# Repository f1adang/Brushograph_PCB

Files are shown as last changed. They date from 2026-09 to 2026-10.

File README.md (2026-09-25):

# Brushograph PCB

This repository contains the KiCad PCB design files for the Brushograph (miniPenzlograf) project, a pen-plotting device designed for creating artistic drawings and patterns.

**A manufacturing-ready PCB-design to run FluidNC on ESP32 including ULN2003 drivers for 3 uni-polar stepper motors (28byj-48)**

Brushograph PCB

**A DIY etchable PCB-design to run FluidNC on ESP32 including ULN2003 drivers for 3 uni-polar stepper motors (28byj-48)**

Brushograph PCB

## About Brushograph

This PCB repository is part of the larger Brushograph project, which explores "Ways of painting with a mechatronic brush" - an intersection between classical artistic techniques and modern technology.

**Main Documentation:**
- [Brushograph Wiki](https://wiki.sgmk-ssam.ch/wiki/Brushograph) - Complete project documentation

## Project Structure

- `Brusograf_PCB/` - Original KiCad project (DIY etchable, single layer)
  - `MASK/` - Mask files in SVG and PDF for PCB silkscreen
- `Brushograf_PCB-china/` - Rev A: manufacturing-ready project and Gerbers
  - `Gerber_Brusograf_black.zip` - Zipped Gerbers ready to upload to a PCB manufacturer
- `Brushograf_PCB-revB/` - Rev B: work in progress (see "Rev B" below)
- `FluidNC_config/` - Configuration for FluidNC firmware
  - `config_pink.yaml` - Rev A config
  - `config_revB.yaml` - Rev B config, adds the pendant UART
- `photos/` - Project photos and documentation images

## Rev B (in progress)

`Brushograf_PCB-revB/` replaces the power section with a USB-C Power Delivery
supply feeding an adjustable motor rail, and adds a pendant port and an ESP
power switch.

**Schematic: complete and verified. PCB: all parts placed, routing still to do.**

The board grows from **198 x 48mm to 198 x 73mm** - 25mm added along the top
edge. Everything from rev A keeps its coordinates; all the new parts live in
the new strip. The RJ-12 needs about 19mm of depth behind the top edge and the
old board only had 11mm before the back-side SPI tracks, which is what forced
the growth.

### What rev B adds

**USB-C Power Delivery is now the only power inlet.** The barrel jack is gone,
along with its reverse-polarity FET and zener. J12 sits on the **left edge**
with the receptacle overhanging it; a CH224K sink controller (U6) requests
**9V**, set by the single 6.8k resistor R24 on CFG1 per the WCH datasheet. A
"PD OK" LED (D17) on the controller's power-good output shows when the contract
is up. VBUS reaches the converters through a 1.5A resettable fuse (F1).

PD offers no 7.5V fixed profile, so the 9V rail feeds two buck converters.

**Adjustable motor rail.** U7 (TPS54202, 2A) steps 9V down to the motor rail,
adjustable with trimmer RV1 over roughly **5.4 - 8.6V**, nominally 7.5V. The
divider is 100k on top and 7.5k plus the 10k trimmer below, against the
TPS54202's 0.596V reference. The wiper is tied to the top of the track, so a
lifted wiper drops the output rather than raising it.

> Running 5V-rated 28BYJ-48 motors at 7.5V is a deliberate overclock: about
> 300mA per motor with two phases energised, roughly 900mA for three. More
> torque and speed, but the motors will run noticeably warm. Set the trimmer to
> 5V first and work up.

**Separate 5V logic rail.** U8 (TPS54202) makes 5.07V for the ESP32. The DevKitC
cannot be fed 7.5V on its 5V pin - its onboard AMS1117 would burn about a watt -
so logic and motors get separate rails.

**ESP power switch.** SW1 is a panel **lever switch on the left edge**, actuator
overhanging the board. It is a 1P2T part used as a simple break: common to the
ESP32, one throw to the board's 5V, the other left open, so the far position
leaves the module running on its own USB supply while the rest of the board
stays powered. D14 (SS14) blocks USB 5V from back-feeding the logic buck.

**RJ-12 pendant port** on the **upper edge**, opening facing off the board. J13
brings UART1 out on GPIO 2 and 15 with switched 5V, behind a 0.5A resettable
fuse (F2), 330R series resistors and TVS clamps.

**J7 repurposed.** Pin 3 used to carry the raw barrel-jack rail straight to the
motors, which would have destroyed them with a 12V adapter. It now carries the
regulated adjustable rail; pin 1 is the 5V logic rail for testing, pin 2 the
motor rail.

### Status

| Area | State |
|---|---|
| Schematic | Complete. 75 parts, 120 nets, netlist verified net by net |
| ERC | At or below rev A in every category |
| Placement | All 36 new footprints placed, zones refilled |
| DRC | No new errors except on J12 - see below |
| Routing | **53 ratsnest connections outstanding** |

### Known DRC findings

- **J12 reports 27 `shorting_items` and 4 `hole_clearance` errors.** These are
  not caused by the placement: the same 31 errors appear with the untouched
  stock footprint alone on an otherwise empty board. The pads have genuine
  0.2-0.7mm gaps and nothing bridges them - zones, solder mask and neighbouring
  copper were each ruled out by experiment. Every USB-C footprint in the KiCad
  library has sub-0.25mm pad gaps, so swapping parts will not help. Worth
  opening in the GUI, where the marker shows interactively what it thinks is
  touching, before committing to fab.
- `allow_soldermask_bridges` is set on J12, which is the correct treatment for a
  fine-pitch connector and clears 23 mask-bridge errors.
- Everything else - 4 mounting-hole annular widths, U4's malformed courtyard,
  5 starved thermals - is inherited unchanged from rev A.

### Open questions

- **The RJ-12 pin order is unverified.** The board uses
  `1 = GND, 2 = +5V, 3 = TX, 4 = RX, 5 = +5V, 6 = GND`, chosen so a standard
  reversing modular cable keeps power and ground on the right contacts and swaps
  TX/RX. bdring's official FluidDial pinout could not be confirmed from public
  documentation - **check it against your cable before building**.
- GPIO2 is an ESP32 strapping pin. It must not be pulled high during boot or the
  chip enters download mode. An idle-high UART receiver at the pendant end is
  fine; anything that actively drives the line is not.

### Known issues carried over from rev A

- The `MISO` and `MOSI` net names are swapped relative to the SD card: net
  `MISO` (GPIO19) goes to the card's CMD/DI pin, which is physically MOSI. The
  card works and the FluidNC config is correct, but **J6's back silkscreen is
  mislabelled** - an external SD module wired to J6 per the silk will have DI
  and DO reversed.
- R1-R12 and C1-C3 still have no values in the schematic, so the BOM is not
  directly orderable.
- The four mounting holes are plated pads with zero annular ring and should be
  non-plated.

## Features

- Custom PCB design for the Brushograph device
- ESP32-based control board with FluidNC firmware support
- Integrated ULN2003 drivers for 3 uni-polar stepper motors (28byj-48)
- DIY etchable single-layer design for easy home fabrication
- Rounded PCB version available
- Configuration files for FluidNC firmware (custom fork for support uni-polar steppers)

## Hardware Configuration

### ESP32 Pin Configuration

Phase order below matches `FluidNC_config/config_revB.yaml`. Note it is the
reverse of what older revisions of this README listed - reversing the phase
order simply reverses the direction of travel.

#### X-Axis Motor (Unipolar)
- Phase 0: GPIO 27
- Phase 1: GPIO 14
- Phase 2: GPIO 13
- Phase 3: GPIO 4

#### Y-Axis Motor (Unipolar)
- Phase 0: GPIO 22
- Phase 1: GPIO 21
- Phase 2: GPIO 17
- Phase 3: GPIO 16

#### Z-Axis Motor (Unipolar)
- Phase 0: GPIO 32
- Phase 1: GPIO 33
- Phase 2: GPIO 25
- Phase 3: GPIO 26

#### SD Card (SPI)
- MOSI: GPIO 19  (net labelled `MISO` on the schematic - see Known issues)
- MISO: GPIO 23  (net labelled `MOSI` on the schematic - see Known issues)
- SCK: GPIO 18
- CS: GPIO 5

#### Pendant UART (rev B)
- TX: GPIO 2 (J13)
- RX: GPIO 15 (J13)

#### Still free
GPIO 34, 35, 36 and 39 (all input-only), GPIO 12, and UART0 on GPIO 1/3.

The four input-only pins are the natural place for limit switches if homing is
added later; they have no internal pull-ups, so each would need an external one.

### Motor Configuration

`config_revB.yaml` in the FluidNC_config directory carries the settings for the
stepper motors. There are no limit switches, so no homing cycles are defined and
every limit pin is `NO_PIN`:

- X/Y axis: 93 steps/mm, 1500 mm/min max rate, 80 mm/s2 acceleration
- Z axis: 108 steps/mm, 1000 mm/min max rate, 40 mm/s2 acceleration

### 28BYJ-48 Stepper Motors

The PCB is designed specifically for the commonly available and inexpensive 28BYJ-48 unipolar stepper motors:
- 5V DC operation
- Gear reduction ratio of 1:64
- Step angle of 5.625° (64 steps per revolution)
- 4-phase operation via ULN2003 driver

## Getting Started

To view or modify the PCB design:
1. Install KiCad (version 6.0 or later recommended)
2. Open the `.kicad_pro` project file in the `Brusograf_PCB` directory
     - For the latest manufacturing-ready version, you can also open the project in `Brushograf_PCB-china/`

For complete setup instructions, including firmware and mechanical assembly, please refer to the [Brushograph Wiki](https://wiki.sgmk-ssam.ch/wiki/Brushograph).

## Manufacturing-ready files

- Latest Gerbers (ZIP, ready for fab): [`Brushograf_PCB-china/Gerber_Brusograf_black.zip`](Brushograf_PCB-china/Gerber_Brusograf_black.zip)
- Gerber folder (all layers and drill files): [`Brushograf_PCB-china/Gerber_Brusograf/`](Brushograf_PCB-china/Gerber_Brusograf/)

## Related Repositories

- [FluidNC for unipolar steppers](https://git.kompot.si/g1smo/FluidNC) - Forked and reworked version of FluidNC to support uni-polar steppers

## License

[Specify license here]

## Credits

Designed by dusjagr

The Brushograph project is based on Dominik Mahnič's "Brušografia" concept, bridging traditional painting and technology.

## Contact

[Your contact information here]

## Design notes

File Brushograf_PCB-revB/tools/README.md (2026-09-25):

# Rev-B generation scripts

One-shot scripts used to derive the rev-B schematic and PCB from the rev-A
project (`../../Brushograf_PCB-china/`). They are kept for reference and so the
revision can be regenerated or audited; ordinary further editing should happen
in KiCad, not here.

Run order, starting from a fresh copy of the rev-A `.kicad_sch` / `.kicad_pcb`:

1. `edit_sch.py`  - sheet -> A2, motor-rail bulk cap, 5V system rail
2. `edit_sch2.py` - USB-C PD input, both buck converters, ESP lever switch,
                    RJ-12 pendant port, and removal of the old linear regulator
                    and barrel jack
3. `edit_pcb.py`  - grows the outline 25mm upward, places all 36 new parts
                    (auto-nudging each clear of existing copper) and re-nets
                    every pad from the exported netlist
4. `fillzones.py` - refills the copper pours. Needs KiCad's bundled Python:
                    /Applications/KiCad/KiCad.app/Contents/Frameworks/\
                    Python.framework/Versions/3.9/bin/python3

Between steps 2 and 3, export the netlist:

    kicad-cli sch export netlist --format kicadsexpr -o revB.net Brushograf_PCB-revB.kicad_sch

Support modules: `kisexp.py` (S-expression reader/writer), `symlib.py` (loads
library symbols and flattens `extends`), `schbuild.py` (symbol placement and
wiring by pin name), `pcbgeom.py` (board occupancy model used to check that a
footprint placement clears existing copper).

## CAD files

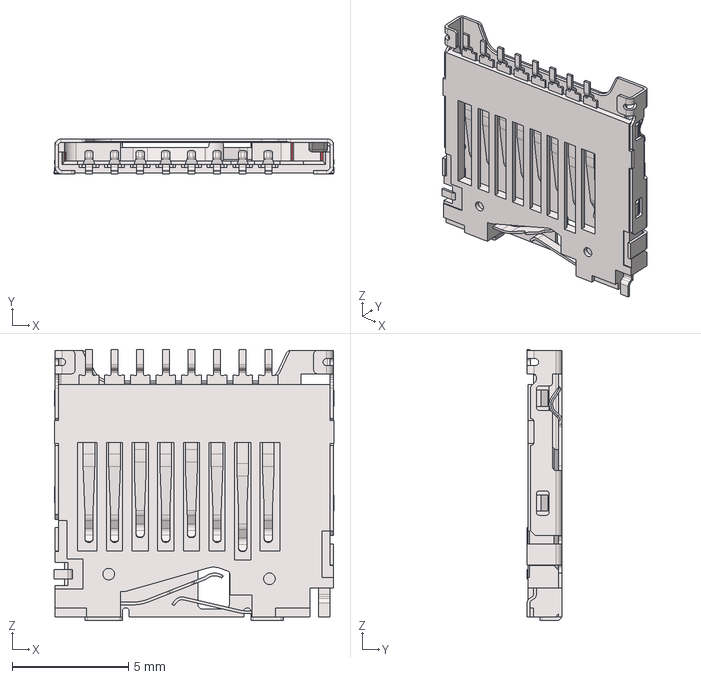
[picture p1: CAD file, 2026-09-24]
Brushograf_PCB-revB/footprints/3d/SD_CARD_MICRO_AMPHENOL_1140084168.step
12.0 x 1.50 x 11.7 mm

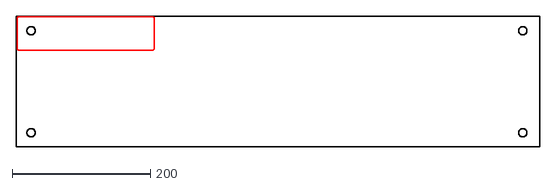
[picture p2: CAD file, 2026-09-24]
Brushograf_PCB-revB/svg2shenzhen/brushograf_edgeCut.dxf
755.9 x 189.0

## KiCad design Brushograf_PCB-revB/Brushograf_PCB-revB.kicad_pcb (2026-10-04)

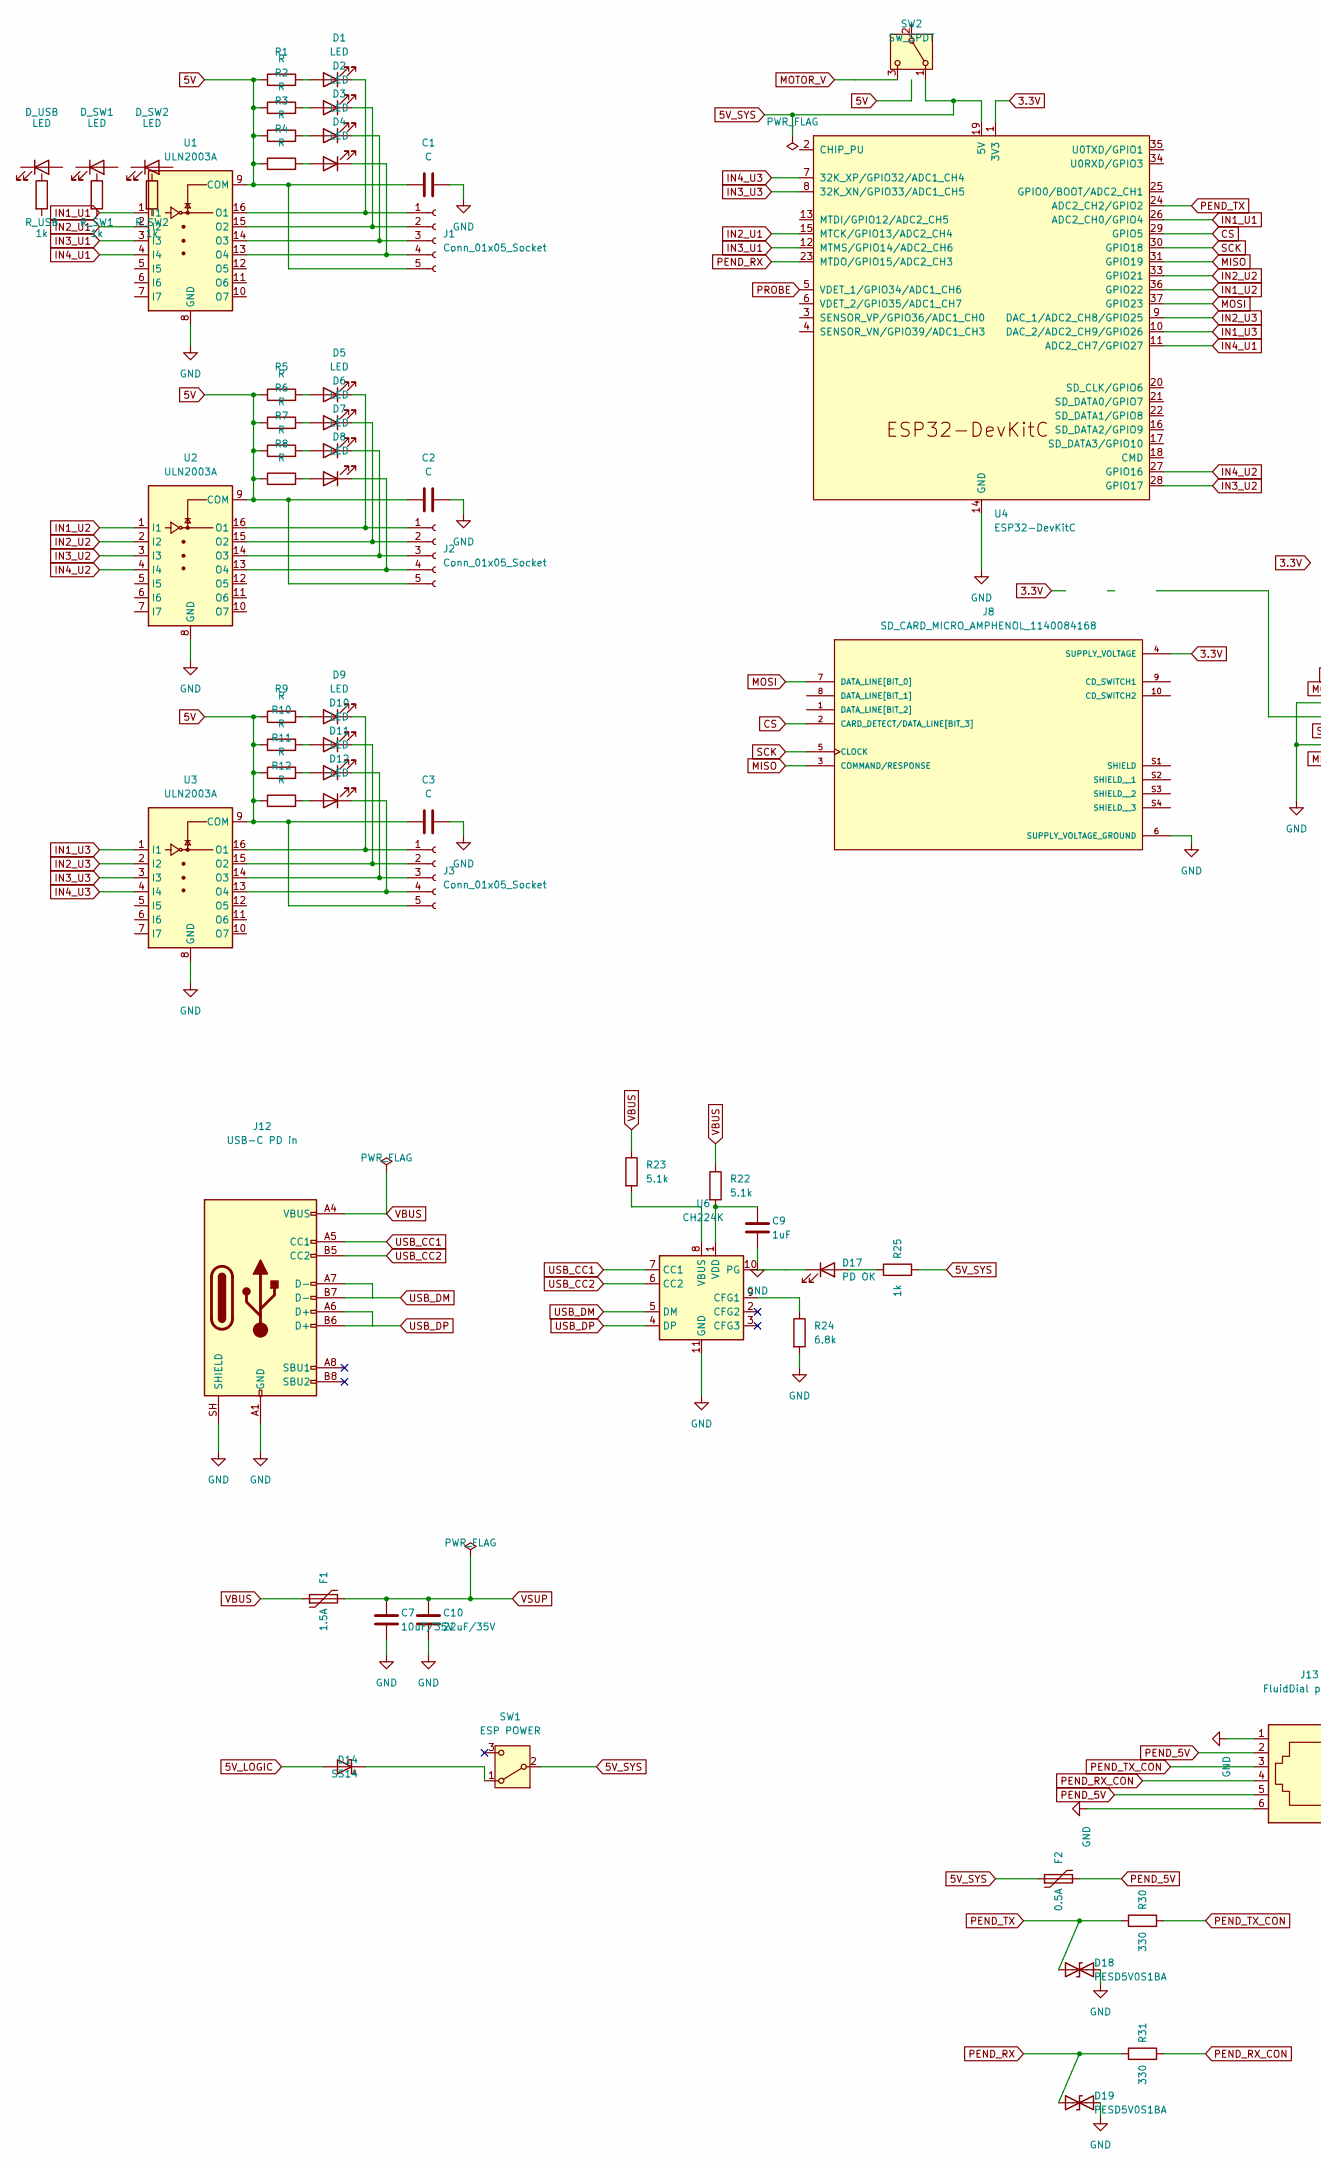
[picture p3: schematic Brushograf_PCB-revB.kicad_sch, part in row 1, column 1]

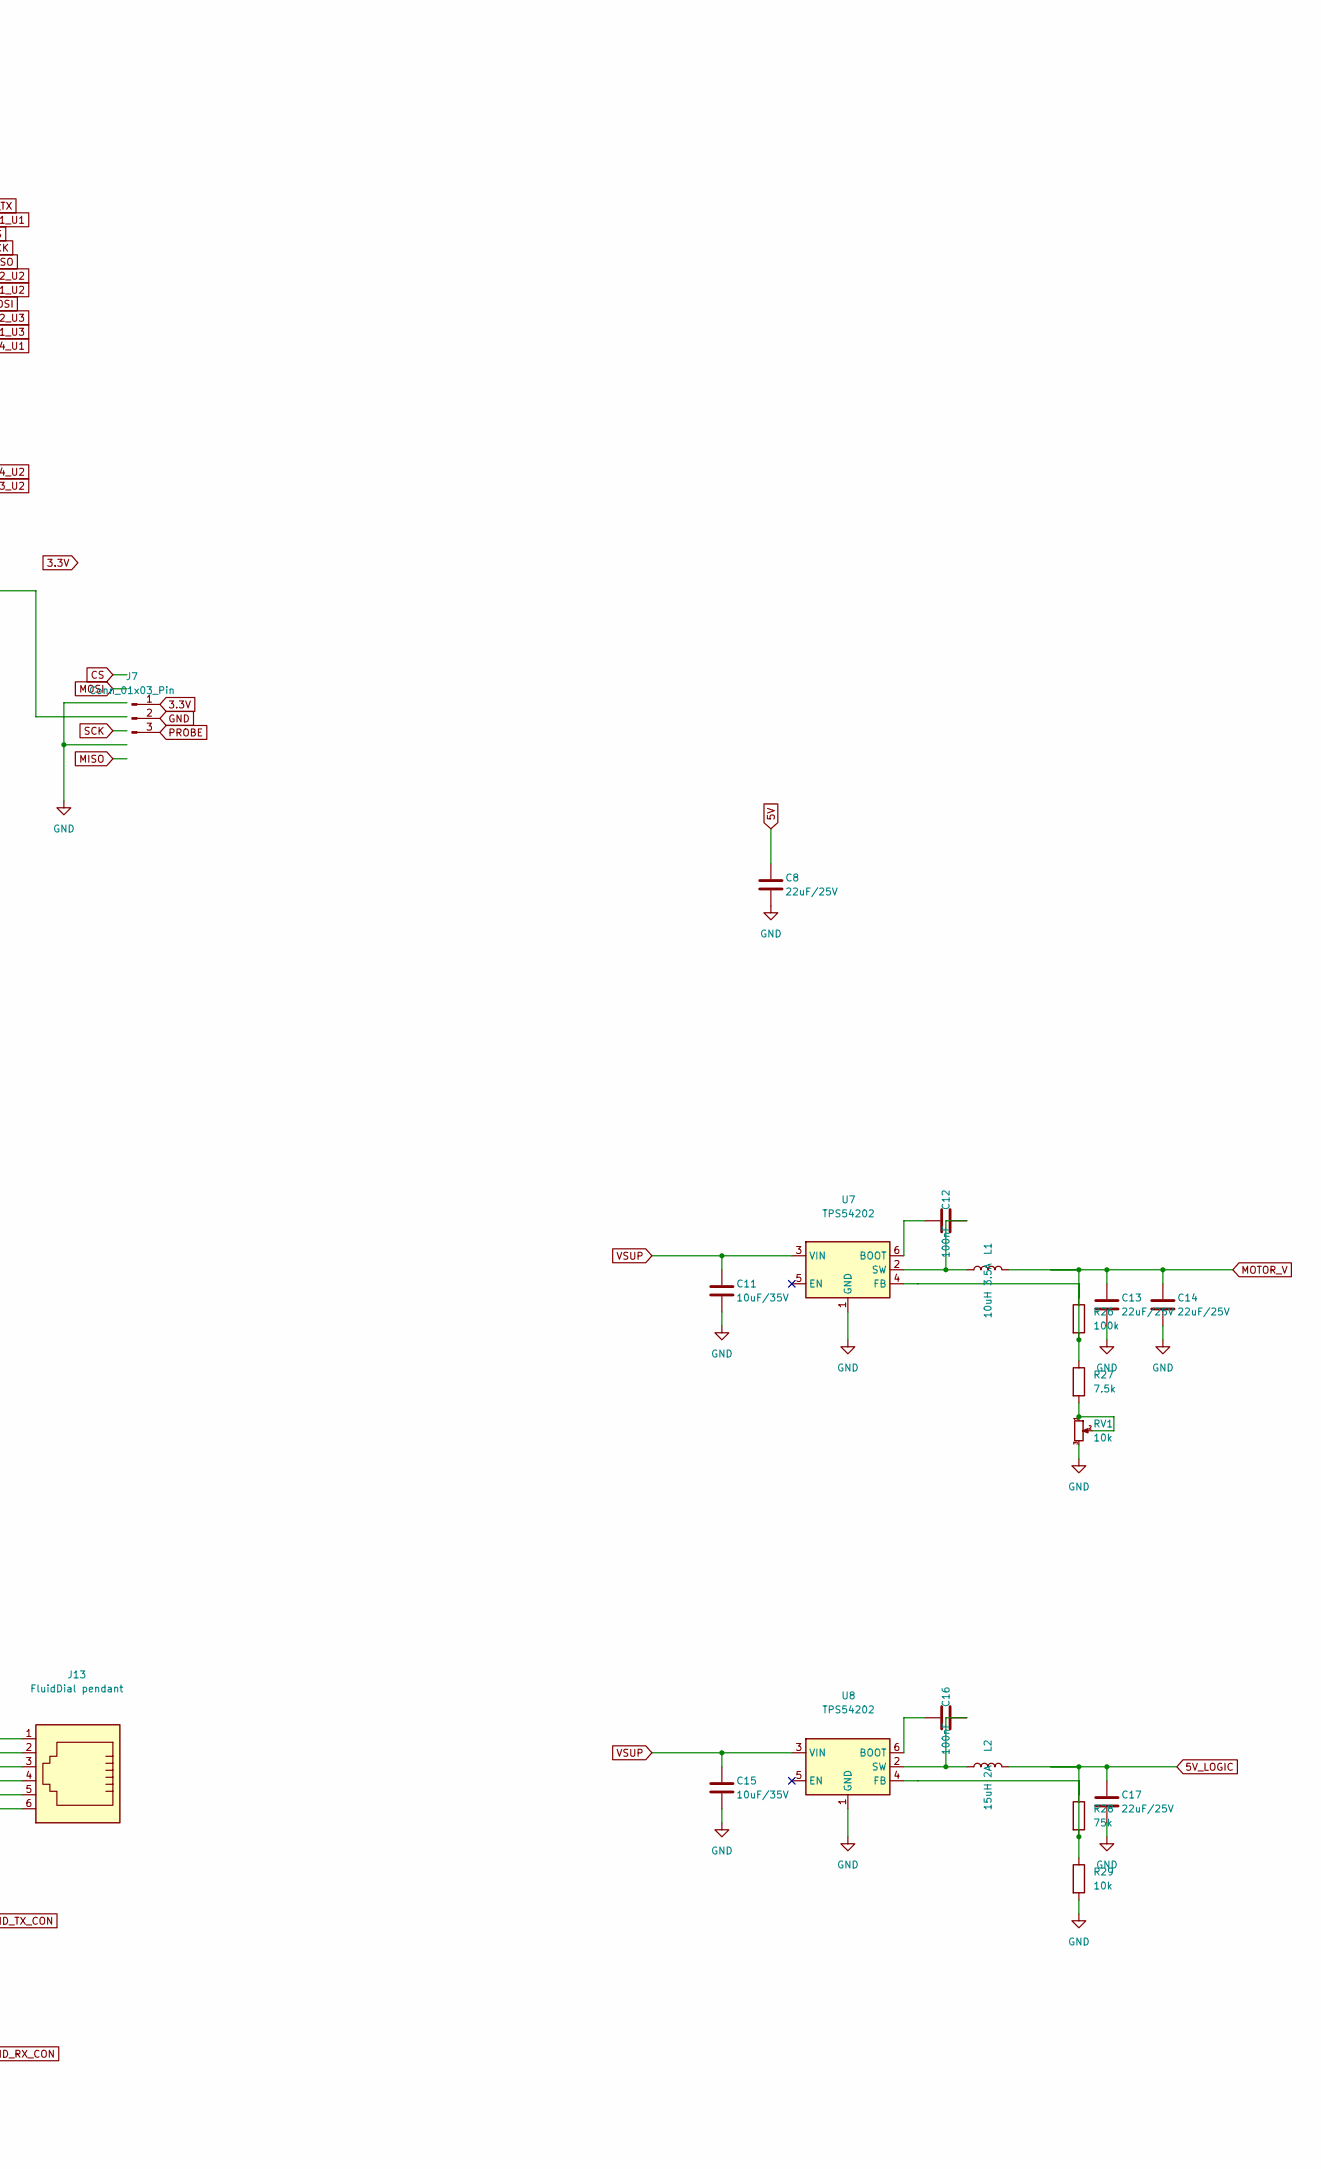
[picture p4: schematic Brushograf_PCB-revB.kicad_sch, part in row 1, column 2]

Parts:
C1, C2, C3: C; C_1210_noGND
C7: 10uF/35V; C_1206_3216Metric_Pad1.33x1.80mm_HandSolder
C8, C13, C14, C17: 22uF/25V; C_1210_3225Metric_Pad1.33x2.70mm_HandSolder
C9: 1uF; C_0603_1608Metric_Pad1.08x0.95mm_HandSolder
C10: 22uF/35V; C_1210_3225Metric_Pad1.33x2.70mm_HandSolder
C11, C15: 10uF/35V; C_1210_3225Metric_Pad1.33x2.70mm_HandSolder
C12, C16: 100nF; C_0603_1608Metric_Pad1.08x0.95mm_HandSolder
D1, D2, D3, D4, D5, D6, D7, D8, D9, D10, D11, D12: LED; LED_D1.8mm_W3.3mm_H2.4mm
D14: SS14; D_SMA_Handsoldering
D17: PD OK; LED_0805_2012Metric_Pad1.15x1.40mm_HandSolder
D18, D19: PESD5V0S1BA; D_SOD-323
D_SW1, D_SW2: LED; LED_D1.8mm_Brushograf
D_USB: LED; LED_D1.8mm_Brushograf
F1: 1.5A; Fuse_1812_4532Metric_Pad1.30x3.40mm_HandSolder
F2: 0.5A; Fuse_1206_3216Metric_Pad1.42x1.75mm_HandSolder
J1, J2, J3: Conn_01x05_Socket; Molex_1x05_P2.54mm_Vertical
J7: Conn_01x03_Pin; PinHeader_1x03_P2.54mm_Vertical
J8: SD_CARD_MICRO_AMPHENOL_1140084168; PARTREV A
J12: USB-C PD in; USB_C_Receptacle_GCT_USB4105-xx-A_16P_TopMnt_Horizontal
J13: FluidDial pendant; RJ12_Amphenol_54601-x06_Horizontal
L1: 10uH 3.5A; L_7.3x7.3_H4.5
L2: 15uH 2A; L_7.3x7.3_H4.5
R1, R2, R3, R4, R5, R6, R7, R8, R9, R10, R11, R12: R; R_1206_noGND
R22, R23: 5.1k; R_0603_1608Metric_Pad0.98x0.95mm_HandSolder
R24: 6.8k; R_0603_1608Metric_Pad0.98x0.95mm_HandSolder
R25: 1k; R_0603_1608Metric_Pad0.98x0.95mm_HandSolder
R26: 100k; R_0603_1608Metric_Pad0.98x0.95mm_HandSolder
R27: 7.5k; R_0603_1608Metric_Pad0.98x0.95mm_HandSolder
R28: 75k; R_0603_1608Metric_Pad0.98x0.95mm_HandSolder
R29: 10k; R_0603_1608Metric_Pad0.98x0.95mm_HandSolder
R30, R31: 330; R_0603_1608Metric_Pad0.98x0.95mm_HandSolder
RV1: 10k; Potentiometer_Bourns_3296W_Vertical
R_SW1, R_SW2: 1k; R_1206_noGND
R_USB: 1k; R_1206_noGND
SW1: ESP POWER; SW_Lever_1P2T_NKK_GW12LxH
SW2: SW_SPDT; SW_Slide_1P2T_EG1218
U1, U2, U3: ULN2003A; DIP-16_W7.62mm_Socket_LongPads
U4: ESP32-DevKitC; ESP32-DevKitC_mod
U6: CH224K; SSOP-10-1EP_3.9x4.9mm_P1mm_EP2.1x3.3mm
U7, U8: TPS54202; SOT-23-6

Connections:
3.3V: J7.1, J8.4 (SUPPLY_VOLTAGE), U4.1 (3V3)
5V: C1.1, C2.1, C3.1, C8.1, J1.5, J2.5, J3.5, R1.1, R2.1, R3.1, R4.1, R5.1, R6.1, R7.1, R8.1, R9.1, R10.1, R11.1, R12.1, R_SW2.1, SW2.2 (B), U1.9 (COM), U2.9 (COM), U3.9 (COM); also elsewhere on the board
5V_LOGIC: C17.1, D14.2 (A), L2.2, R28.1; also elsewhere on the board
5V_SYS: F2.1, R25.2, R_SW1.1, SW1.2 (B), SW2.1 (A), U4.19 (5V)
CS: J8.2 (CARD_DETECT/DATA_LINE[BIT_3]), U4.29 (GPIO5)
GND: C1.2, C2.2, C3.2, C7.2, C8.2, C9.2, C10.2, C11.2, C13.2, C14.2, C15.2, C17.2, D18.2 (A2), D19.2 (A2), D_SW1.2 (A), D_SW2.2 (A), D_USB.2 (A), J7.2, J8.6 (SUPPLY_VOLTAGE_GROUND), J12.A1 (GND), J12.A12 (GND), J12.B1 (GND), J12.B12 (GND), J12.SH (SHIELD), J13.1, J13.6, R24.2, R29.2, RV1.3, U1.8 (GND), U2.8 (GND), U3.8 (GND), U4.14 (GND), U4.32 (GND), U4.38 (GND), U6.11 (GND), U7.1 (GND), U8.1 (GND); also elsewhere on the board
IN1_U1: U1.1 (I1), U4.26 (ADC2_CH0/GPIO4); also elsewhere on the board
IN1_U2: U2.1 (I1), U4.36 (GPIO22); also elsewhere on the board
IN1_U3: U3.1 (I1), U4.10 (DAC_2/ADC2_CH9/GPIO26); also elsewhere on the board
IN2_U1: U1.2 (I2), U4.15 (MTCK/GPIO13/ADC2_CH4); also elsewhere on the board
IN2_U2: U2.2 (I2), U4.33 (GPIO21); also elsewhere on the board
IN2_U3: U3.2 (I2), U4.9 (DAC_1/ADC2_CH8/GPIO25); also elsewhere on the board
IN3_U1: U1.3 (I3), U4.12 (MTMS/GPIO14/ADC2_CH6); also elsewhere on the board
IN3_U2: U2.3 (I3), U4.28 (GPIO17); also elsewhere on the board
IN3_U3: U3.3 (I3), U4.8 (32K_XN/GPIO33/ADC1_CH5); also elsewhere on the board
IN4_U1: U1.4 (I4), U4.11 (ADC2_CH7/GPIO27); also elsewhere on the board
IN4_U2: U2.4 (I4), U4.27 (GPIO16); also elsewhere on the board
IN4_U3: U3.4 (I4), U4.7 (32K_XP/GPIO32/ADC1_CH4); also elsewhere on the board
MISO: J8.3 (COMMAND/RESPONSE), U4.31 (GPIO19)
MOSI: J8.7 (DATA_LINE[BIT_0]), U4.37 (GPIO23)
unnamed: D1.1 (K), J1.1, U1.16 (O1)
unnamed: D2.2 (A), R2.2
unnamed: D2.1 (K), J1.2, U1.15 (O2)
unnamed: D3.2 (A), R3.2
unnamed: D3.1 (K), J1.3, U1.14 (O3)
unnamed: D4.2 (A), R4.2
unnamed: D4.1 (K), J1.4, U1.13 (O4)
unnamed: D5.2 (A), R5.2
unnamed: D5.1 (K), J2.1, U2.16 (O1)
unnamed: D6.2 (A), R6.2
unnamed: D6.1 (K), J2.2, U2.15 (O2)
unnamed: D7.2 (A), R7.2
unnamed: D7.1 (K), J2.3, U2.14 (O3)
unnamed: D8.2 (A), R8.2
unnamed: D8.1 (K), J2.4, U2.13 (O4)
unnamed: D9.2 (A), R9.2
unnamed: D9.1 (K), J3.1, U3.16 (O1)
unnamed: D10.2 (A), R10.2
unnamed: D10.1 (K), J3.2, U3.15 (O2)
unnamed: D11.2 (A), R11.2
unnamed: D11.1 (K), J3.3, U3.14 (O3)
unnamed: D12.2 (A), R12.2
unnamed: D12.1 (K), J3.4, U3.13 (O4)
unnamed: D14.1 (K), SW1.1 (A)
unnamed: D17.2 (A), R25.1
unnamed: D17.1 (K), U6.10 (PG)
unnamed: D_SW1.1 (K), R_SW1.2
unnamed: D_SW2.1 (K), R_SW2.2
unnamed: D_USB.1 (K), R_USB.2
unnamed: R27.2, RV1.1, RV1.2
unnamed: R24.1, U6.9 (CFG1)
unnamed: R23.2, U6.8 (VBUS)
unnamed: C9.1, R22.2, U6.1 (VDD)
unnamed: C12.1, U7.6 (BOOT)
unnamed: R26.2, R27.1, U7.4 (FB)
unnamed: C12.2, L1.1, U7.2 (SW)
unnamed: C16.1, U8.6 (BOOT)
unnamed: R28.2, R29.1, U8.4 (FB)
unnamed: C16.2, L2.1, U8.2 (SW)
PEND_5V: F2.2, J13.2, J13.5
PEND_RX: D19.1 (A1), R31.1, U4.23 (MTDO/GPIO15/ADC2_CH3)
PEND_RX_CON: J13.4, R31.2
PEND_TX: D18.1 (A1), R30.1, U4.24 (ADC2_CH2/GPIO2)
PEND_TX_CON: J13.3, R30.2
PROBE: J7.3, U4.5 (VDET_1/GPIO34/ADC1_CH6)
SCK: J8.5 (CLOCK), U4.30 (GPIO18)
USB_CC1: J12.A5 (CC1), U6.7 (CC1)
USB_CC2: J12.B5 (CC2), U6.6 (CC2)
USB_DM: J12.A7 (D-), J12.B7 (D-), U6.5 (DM)
USB_DP: J12.A6 (D+), J12.B6 (D+), U6.4 (DP)
VBUS: F1.1, J12.A4 (VBUS), J12.A9 (VBUS), J12.B4 (VBUS), J12.B9 (VBUS), R22.1, R23.1, R_USB.1
VSUP: C7.1, C10.1, C11.1, C15.1, F1.2, U7.3 (VIN), U8.3 (VIN)

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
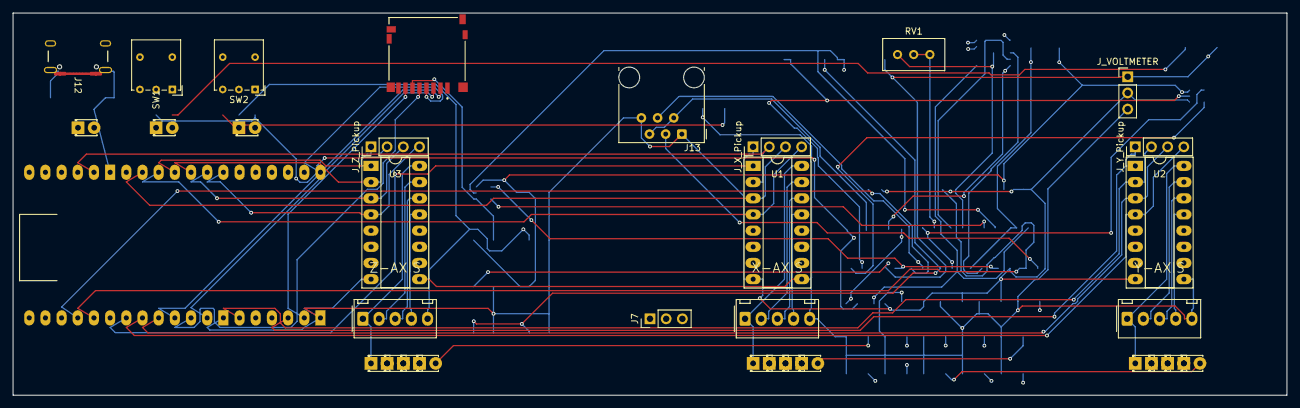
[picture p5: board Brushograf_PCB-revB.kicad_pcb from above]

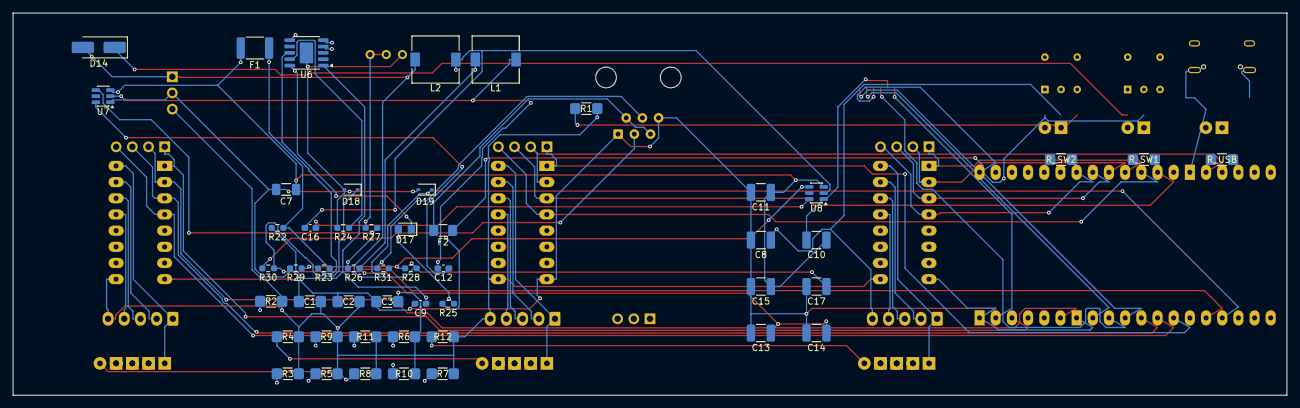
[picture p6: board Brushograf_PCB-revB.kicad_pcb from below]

Board: 2 copper layers, 200.0 x 60.0 mm, 83 parts (50 on the bottom side), 73 nets.

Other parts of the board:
J_VOLTMETER: PinHeader_1x03_P2.54mm_Vertical
J_X_Pickup: PinHeader_1x04_P2.54mm_Vertical
J_Y_Pickup: PinHeader_1x04_P2.54mm_Vertical
J_Z_Pickup: PinHeader_1x04_P2.54mm_Vertical

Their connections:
5V: J_VOLTMETER.3; also elsewhere on the board
5V_LOGIC: J_VOLTMETER.1; also elsewhere on the board
GND: J_VOLTMETER.2; also elsewhere on the board
IN1_U1: J_X_Pickup.1; also elsewhere on the board
IN1_U2: J_Y_Pickup.1; also elsewhere on the board
IN1_U3: J_Z_Pickup.1; also elsewhere on the board
IN2_U1: J_X_Pickup.2; also elsewhere on the board
IN2_U2: J_Y_Pickup.2; also elsewhere on the board
IN2_U3: J_Z_Pickup.2; also elsewhere on the board
IN3_U1: J_X_Pickup.3; also elsewhere on the board
IN3_U2: J_Y_Pickup.3; also elsewhere on the board
IN3_U3: J_Z_Pickup.3; also elsewhere on the board
IN4_U1: J_X_Pickup.4; also elsewhere on the board
IN4_U2: J_Y_Pickup.4; also elsewhere on the board
IN4_U3: J_Z_Pickup.4; also elsewhere on the board

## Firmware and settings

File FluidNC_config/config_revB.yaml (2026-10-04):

# Brushograph PCB rev B - FluidNC configuration
#
# Adds the RJ-12 pendant port on UART1; motor and SPI/SD settings are unchanged
# from the rev A config.  There are no limit switches on this board, so no
# homing cycles are defined and every limit pin is NO_PIN.
name: Brushograph rev B (ULN2003 unipolar)
board: ESP32

stepping:
  engine: RMT
  idle_ms: 250
  dir_delay_us: 1
  pulse_us: 8
  disable_delay_us: 0

axes:
  shared_stepper_disable_pin: NO_PIN

  x:
    steps_per_mm: 93
    max_rate_mm_per_min: 1500
    acceleration_mm_per_sec2: 80
    max_travel_mm: 200
    motor0:
      limit_neg_pin: NO_PIN
      limit_pos_pin: NO_PIN
      limit_all_pin: NO_PIN
      unipolar:
        phase0_pin: gpio.27
        phase1_pin: gpio.14
        phase2_pin: gpio.13
        phase3_pin: gpio.4

  y:
    steps_per_mm: 93
    max_rate_mm_per_min: 1500
    acceleration_mm_per_sec2: 80
    max_travel_mm: 200
    motor0:
      limit_neg_pin: NO_PIN
      limit_pos_pin: NO_PIN
      limit_all_pin: NO_PIN
      unipolar:
        phase0_pin: gpio.22
        phase1_pin: gpio.21
        phase2_pin: gpio.17
        phase3_pin: gpio.16

  z:
    steps_per_mm: 108
    max_rate_mm_per_min: 1000
    acceleration_mm_per_sec2: 40
    max_travel_mm: 100
    motor0:
      limit_neg_pin: NO_PIN
      limit_pos_pin: NO_PIN
      limit_all_pin: NO_PIN
      unipolar:
        phase0_pin: gpio.32
        phase1_pin: gpio.33
        phase2_pin: gpio.25
        phase3_pin: gpio.26

macros:
  startup_line0: G53 Z10 & G53 Z0
  macro0:
  macro1:
  macro2:
  after_reset:

# The RJ-12 pendant port (J13) brings UART1 out to a FluidDial on GPIO 2 and 15,
# with 5V from the switched logic rail behind a 0.5A resettable fuse.
#
# GPIO2 is an ESP32 strapping pin: it must not be pulled high while the board
# boots or the chip drops into download mode. The pendant end must therefore
# leave it alone until FluidNC has started - which a normal idle-high UART
# receiver does, but check any pendant that drives the line actively.
uart1:
  txd_pin: gpio.2
  rxd_pin: gpio.15
  rts_pin: NO_PIN
  cts_pin: NO_PIN
  baud: 115200
  mode: 8N1

uart_channel1:
  uart_num: 1
  report_interval_ms: 75
  message_level: Info

spi:
  miso_pin: gpio.23
  mosi_pin: gpio.19
  sck_pin: gpio.18

sdcard:
  card_detect_pin: NO_PIN
  cs_pin: gpio.5

probe:
  pin: gpio.34:low

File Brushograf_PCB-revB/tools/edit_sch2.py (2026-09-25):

#!/usr/bin/env python3
"""Rev-B stage 2: USB-C PD input, adjustable motor buck, 5V logic buck,
ESP power switch and the RJ-12 FluidDial pendant port."""
import sys, os
sys.path.insert(0, os.path.dirname(os.path.abspath(__file__)))
from kisexp import parse, dump, find, first, prop, propval, Str, f
from schbuild import Sheet, fmt, uid
import symlib

SCH = '/Users/gandalf/Documents/fun/Brushograph_PCB/Brushograf_PCB-revB/Brushograf_PCB-revB.kicad_sch'
doc = parse(open(SCH).read())
SU = str(first(doc, 'uuid')[1])
sh = Sheet(SU)

# footprint shorthands
R06   = 'Resistor_SMD:R_0603_1608Metric_Pad0.98x0.95mm_HandSolder'
R12F  = 'Resistor_SMD:R_1206_3216Metric_Pad1.30x1.75mm_HandSolder'
C06   = 'Capacitor_SMD:C_0603_1608Metric_Pad1.08x0.95mm_HandSolder'
C12F  = 'Capacitor_SMD:C_1206_3216Metric_Pad1.33x1.80mm_HandSolder'
C1210 = 'Capacitor_SMD:C_1210_3225Metric_Pad1.33x2.70mm_HandSolder'
SOT6  = 'Package_TO_SOT_SMD:SOT-23-6'
SOD323= 'Diode_SMD:D_SOD-323'
SMA   = 'Diode_SMD:D_SMA_Handsoldering'
LFP   = 'Inductor_SMD:L_7.3x7.3_H4.5'
USBC  = 'Connector_USB:USB_C_Receptacle_GCT_USB4105-xx-A_16P_TopMnt_Horizontal'
SSOP10= 'Package_SO:SSOP-10-1EP_3.9x4.9mm_P1mm_EP2.1x3.3mm'
RJ12FP= 'Connector_RJ:RJ12_Amphenol_54601-x06_Horizontal'
TRIM   = 'Potentiometer_THT:Potentiometer_Bourns_3296W_Vertical'
LEVER  = 'Button_Switch_THT:SW_Lever_1P2T_NKK_GW12LxH'
FUSE06 = 'Fuse:Fuse_1206_3216Metric_Pad1.42x1.75mm_HandSolder'

def stub(part, pin, net, length=7.62, rot=None):
    """Short wire out of a pin, ending in a global label."""
    px, py = part.p(pin)
    dx, dy = px - part.x, py - part.y
    if abs(dx) >= abs(dy):
        ex, ey = px + (length if dx > 0 else -length), py
        r = 0 if dx > 0 else 180
    else:
        ex, ey = px, py + (length if dy > 0 else -length)
        r = 90 if dy < 0 else 270
    sh.wire(px, py, ex, ey)
    sh.label(net, ex, ey, rot if rot is not None else r)
    return (ex, ey)

def gnd_stub(part, pin, length=7.62):
    px, py = part.p(pin)
    sh.wire(px, py, px, py + length)
    sh.gnd(px, py + length)


# ============================== rework of the existing sheet ==============================
# The linear regulator and its blocking diode are replaced by the two bucks
# below, so U5, the old D14 and the wiring between them come out.
def drop_symbol(ref):
    for s in find(doc, 'symbol'):
        if propval(s, 'Reference') == ref:
            doc.remove(s); return True
    return False

def drop_wire(x1, y1, x2, y2):
    for w in find(doc, 'wire'):
        pts = sorted((round(f(p[1]), 3), round(f(p[2]), 3)) for p in first(w, 'pts')[1:])
        if pts == sorted([(x1, y1), (x2, y2)]):
            doc.remove(w); return True
    return False

def drop_junction(x, y):
    for j in find(doc, 'junction'):
        a = first(j, 'at')
        if abs(f(a[1]) - x) < 1e-3 and abs(f(a[2]) - y) < 1e-3:
            doc.remove(j); return True
    return False

def drop_gnd_at(x, y):
    for s in find(doc, 'symbol'):
        if str(first(s, 'lib_id')[1]) != 'power:GND':
            continue
        a = first(s, 'at')
        if abs(f(a[1]) - x) < 1e-3 and abs(f(a[2]) - y) < 1e-3:
            doc.remove(s); return True
    return False

assert drop_symbol('U5'), 'U5 not found'
assert drop_symbol('D14'), 'old D14 not found'
for seg in [(125.73, 22.86, 128.27, 22.86),   # U5 IN stub
            (125.73, 13.97, 125.73, 22.86),
            (167.64, 13.97, 125.73, 13.97),
            (167.64, 24.13, 167.64, 13.97),
            (143.51, 22.86, 143.51, 30.48),   # U5 OUT stub
            (135.89, 30.48, 135.89, 33.02)]:  # U5 GND stub
    assert drop_wire(*seg), f'wire {seg} not found'
assert drop_junction(167.64, 24.13), 'junction not found'
assert drop_gnd_at(135.89, 33.02), 'U5 GND symbol not found'

# The barrel jack goes too: USB-C PD is now the only power inlet.
assert drop_symbol('J5'), 'J5 not found'
for seg in [(110.49, 137.16, 115.57, 137.16),
            (115.57, 132.08, 115.57, 124.46),
            (115.57, 124.46, 107.95, 124.46),
            (107.95, 124.46, 107.95, 127.0)]:
    assert drop_wire(*seg), f'J5 wire {seg} not found'
assert drop_gnd_at(107.95, 127.0), 'J5 GND symbol not found'
for gl in list(find(doc, 'global_label')):
    a = first(gl, 'at')
    if abs(f(a[1]) - 110.49) < 0.01 and abs(f(a[2]) - 137.16) < 0.01:
        doc.remove(gl); break
else:
    raise SystemExit('ERROR: barrel-jack label not found')

# what is left of the old regulator output run now becomes the 5V system rail
sh.label('5V_SYS', 151.13, 30.48, 180)

# J7 pin 3 used to be the raw barrel-jack rail, which would now be 9-20V and
# would destroy the motors. It becomes the adjustable motor rail instead.
for gl in find(doc, 'global_label'):
    a = first(gl, 'at')
    if str(gl[1]) == '5V-EXT' and abs(f(a[1]) - 163.83) < 0.01:
        gl[1] = Str('MOTOR_V'); break
else:
    raise SystemExit('ERROR: J7 5V-EXT label not found')

# pendant UART out to the ESP32
sh.wire(157.48, 57.15, 152.4, 57.15)          # U4 pin 23, GPIO15
sh.label('PEND_RX', 152.4, 57.15, 180)
sh.wire(223.52, 46.99, 228.6, 46.99)          # U4 pin 24, GPIO2
sh.label('PEND_TX', 228.6, 46.99, 0)

# =====================================================  USB-C + CH224K PD sink
J12 = sh.place('Connector', 'USB_C_Receptacle_USB2.0_16P', 'J12', 'USB-C PD in',
               USBC, 60, 245, 0, ref_at=(60, 214, None), val_at=(60, 216.54, None))
sh.wire(*J12.p('A1'), J12.p('A1')[0], J12.p('A1')[1] + 5.08)
sh.gnd(J12.p('A1')[0], J12.p('A1')[1] + 5.08)
sh.wire(*J12.p('SH'), J12.p('SH')[0], J12.p('SH')[1] + 5.08)
sh.gnd(J12.p('SH')[0], J12.p('SH')[1] + 5.08)
vb_pt = stub(J12, 'A4', 'VBUS')             # all four VBUS pins share one point
# VBUS is fed by the connector, so flag it as a source for ERC
sh.wire(vb_pt[0], vb_pt[1], vb_pt[0], vb_pt[1] - 7.62)
sh.pwrflag(vb_pt[0], vb_pt[1] - 7.62, 0)
stub(J12, 'A5', 'USB_CC1')
stub(J12, 'B5', 'USB_CC2')
# D+ / D- : the A and B contacts are separate points, tie each pair together
for a, b, net in (('A6', 'B6', 'USB_DP'), ('A7', 'B7', 'USB_DM')):
    ax, ay = J12.p(a); bx, by = J12.p(b)
    sh.wire(ax, ay, ax + 5.08, ay); sh.wire(bx, by, bx + 5.08, by)
    sh.wire(ax + 5.08, ay, bx + 5.08, by)
    sh.wire(bx + 5.08, by, bx + 10.16, by)
    sh.label(net, bx + 10.16, by, 0)
for nc in ('A8', 'B8'):
    x, y = J12.p(nc)
    sh.items.append(['no_connect', ['at', fmt(x), fmt(y)], ['uuid', uid('nc')]])
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

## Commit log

2026-09-24 Add rev B: USB-C PD power section, pendant port, ESP power switch
    Rev B replaces the power stage and adds a FluidDial pendant port. The
    schematic is complete and verified; the PCB layout for the new power
    section is not done yet because the board has to grow first.
    Power stage (replaces the L7805, which was thermally unviable - at 12V in
    it dissipated ~1.75W in a bare DPAK even powering only the ESP32):
    - USB-C receptacle (J12) with a CH224K PD sink (U6) requesting 9V, set
    by the single 6.8k on CFG1 per the WCH datasheet. PD-OK LED on the
    power-good output.
    - U7 (TPS54202) steps 9V down to an adjustable motor rail, roughly
    5.4-8.6V via trimmer RV1, nominally 7.5V. The wiper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
    [Brushograf_PCB-revB.kicad_pcb, Brushograf_PCB-revB.kicad_sch, SD_CARD_MICRO_AMPHENOL_1140084168.step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]
2026-09-25 USB-C as the only inlet; lever switch and RJ-12 placed on the board edges
    Grows the outline 25mm along the top (198x48 -> 198x73mm) and places every
    new part. The RJ-12 needs ~19mm behind the top edge and the old board had
    11mm before the back-side SPI tracks, which is what forced the growth.
    Everything from rev A keeps its coordinates.
    - The barrel jack is now gone, with its reverse-polarity FET, zener and
    gate resistor. USB-C is the sole power inlet: VBUS through a 1.5A
    polyfuse straight to the rail feeding both converters.
    - J12 sits on the left edge, receptacle overhanging it.
    - SW1 becomes an NKK GW12L panel lever switch on the left edge with the
    actuator overhanging,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
    [Brushograf_PCB-revB.kicad_pcb, Brushograf_PCB-revB.kicad_sch]
2026-09-28 Update SW2 to switch, move SW1 for hole clearance, relocate SD card holder to edge
    [Brushograf_PCB-revB.kicad_pcb, Brushograf_PCB-revB.kicad_sch]
2026-09-28 Fix component packing and shrink board outline correctly
    [Brushograf_PCB-revB.kicad_pcb]
2026-09-28 Repack components with ESP32 clearance, edge alignment for SD, and LED grouping
    [Brushograf_PCB-revB.kicad_pcb]
2026-09-28 Align Top/Left edge components per user request
    [Brushograf_PCB-revB.kicad_pcb]
2026-09-28 Auto-route traces using FreeRouting
    [Brushograf_PCB-revB.kicad_pcb]
2026-09-28 Diagonal stretch outline, labeled axes, fix J12, isolate U4
    [Brushograf_PCB-revB.kicad_pcb]
2026-09-28 Lengthwise board stretch, labeled X/Y/Z, refined J12/U4 left edge
    [Brushograf_PCB-revB.kicad_pcb]
2026-09-28 Motor connectors/drivers to bottom edge (Z, X, Y), preserve length
    [Brushograf_PCB-revB.kicad_pcb]
2026-09-28 Make board much wider (230mm) and unstack sockets/connectors
    [Brushograf_PCB-revB.kicad_pcb]
2026-09-28 Move motor LEDs below connectors, flush mount USB-C edge
    [Brushograf_PCB-revB.kicad_pcb]
2026-09-28 Mathematically center align Motor LEDs, Drivers, and Connectors
    [Brushograf_PCB-revB.kicad_pcb]
2026-09-28 Ultra-wide strip form factor, USB-C facing up and edge-aligned
    [Brushograf_PCB-revB.kicad_pcb]
2026-09-28 Optimize form factor to highly compact 200x55mm strip layout
    [Brushograf_PCB-revB.kicad_pcb]
2026-09-28 Auto-route compact strip layout via FreeRouting
    [Brushograf_PCB-revB.kicad_pcb]
2026-09-28 Shift motors left symmetrically, add piezo pickup headers
    [Brushograf_PCB-revB.kicad_pcb]
2026-09-28 Rotate piezo pickup headers to be horizontal and mathematically center them
    [Brushograf_PCB-revB.kicad_pcb]
2026-09-28 Revert to tightly optimized 200x55 layout while preserving left-shifted motors and piezo headers
    [Brushograf_PCB-revB.kicad_pcb]
2026-09-28 Fix component spillage and add voltmeter header
    [Brushograf_PCB-revB.kicad_pcb]
2026-09-28 Auto-route densely packed 200x60 layout with piezo headers and voltmeter
    [Brushograf_PCB-revB.kicad_pcb]
2026-10-04 Remove unused components R13, R14, and J6
    [Brushograf_PCB-revB.kicad_sch]
2026-10-04 Add probe configuration on GPIO 34
    [config_revB.yaml]
2026-10-04 Add probe connector J7 and labels
    [Brushograf_PCB-revB.kicad_sch]
2026-10-04 Move J7 to Y=50 and swap GND/PROBE pinout
    [Brushograf_PCB-revB.kicad_pcb, Brushograf_PCB-revB.kicad_sch]
2026-10-04 Change J7 to horizontal header at Y=58 and rotate 90 deg
    [Brushograf_PCB-revB.kicad_pcb]
2026-10-04 Change J7 to Vertical header
    [Brushograf_PCB-revB.kicad_pcb]
2026-10-04 Move USB-C to Y=15.84 and Switches to Y=22. Add LEDs with Brushograph footprints
    [Brushograf_PCB-revB.kicad_pcb, Brushograf_PCB-revB.kicad_sch]
2026-10-04 Fix resistor footprints (replace RV1 potentiometer template with R1 1206 template)
    [Brushograf_PCB-revB.kicad_pcb]
2026-10-04 Align LEDs and resistors under USB and Switches
    [Brushograf_PCB-revB.kicad_pcb]
2026-10-04 Move ESP32 module (U4) and attached tracks 2.54mm inwards to fix pad overhang
    [Brushograf_PCB-revB.kicad_pcb]
